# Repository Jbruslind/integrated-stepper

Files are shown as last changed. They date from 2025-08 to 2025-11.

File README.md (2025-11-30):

# Integrated Stepper

Full stepper motor control w/ local feedback and power conversion in a small package. The main idea was to have an all-in-one solution PCB which would run some open source FOC firmware (Simple-FOC for now) and have some higher level control through ethernet, CAN, or UART (CAN for now). 

Power and comms should be provided on the same wire harness either using RJ45 (original idea) or the XT30 + 2wire connector (current design) which allows for high voltage + current and 2wire comms. These can then be daisy chained to as many nodes as possible (limited by wire lengths for the most part)

## Key Features

- **High Precision:** Sub-degree positioning accuracy
- **Smooth Motion:** Advanced motion planning and acceleration control
- **Multiple Modes:** Position, velocity, and torque control modes
- **Microstepping:** Configurable microstepping for smooth operation
- **Communication:** UART, SPI, I2C, and CAN bus support

## Hardware Specifications

- **Current Rating:** Configurable current output up to 2A per phase continous
- **Voltage Range:** 8V to 35V operation
- **Microstepping:** Up to 256 microsteps per full step
- **Protection:** Overcurrent, overvoltage, and thermal protection

## Applications

- Industrial automation and conveyor systems
- Robotics and robot arms
- CNC machines and 3D printers
- Laser positioning systems
- Research and prototyping

## License

This project is open source and available under the MIT License.

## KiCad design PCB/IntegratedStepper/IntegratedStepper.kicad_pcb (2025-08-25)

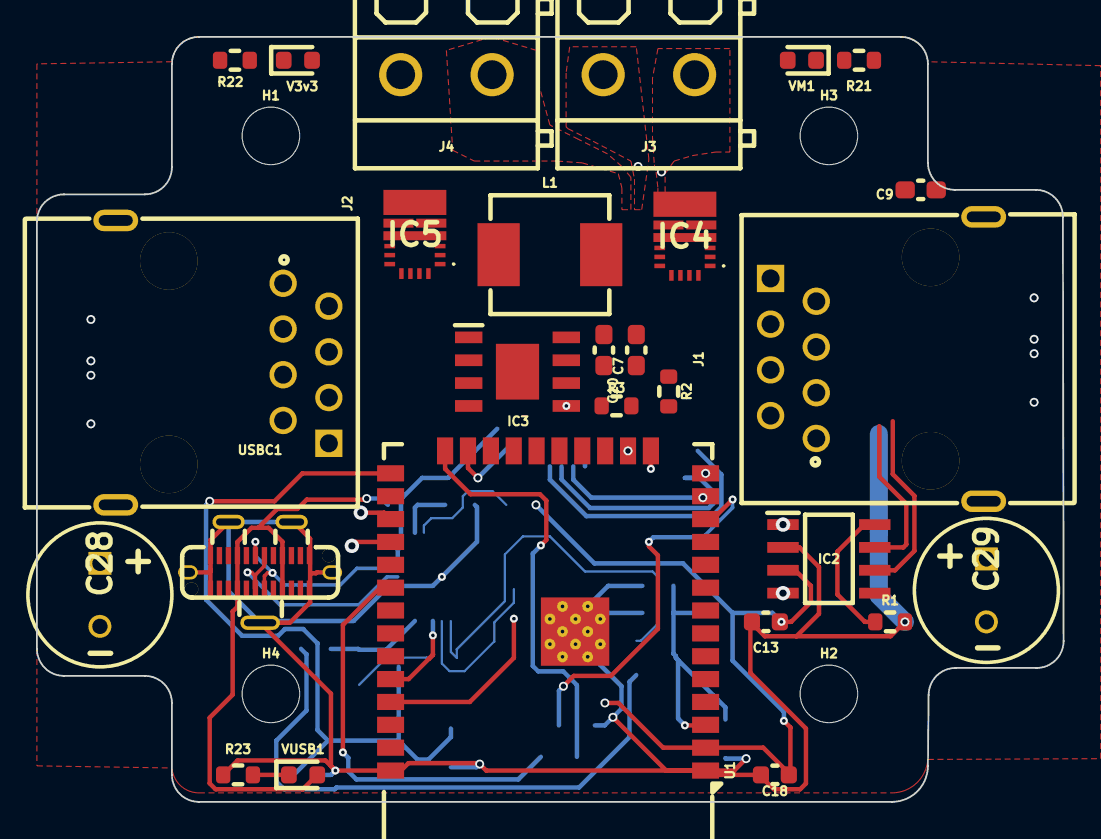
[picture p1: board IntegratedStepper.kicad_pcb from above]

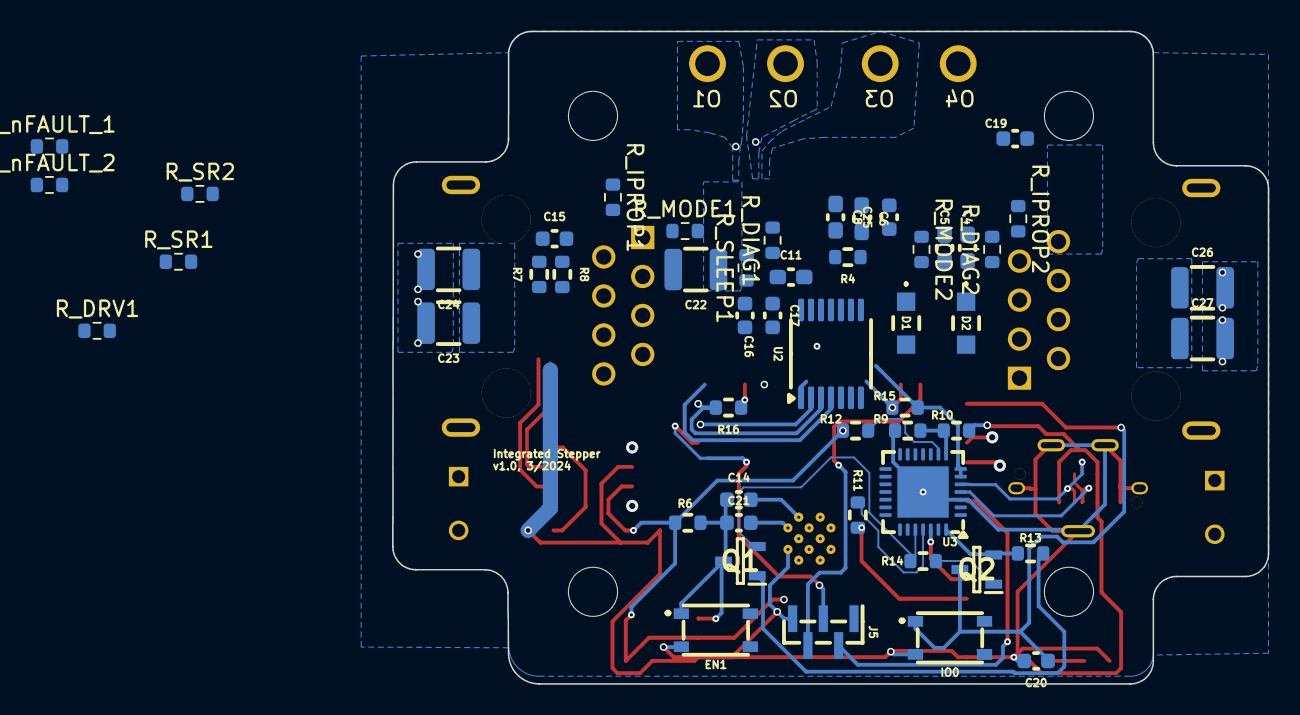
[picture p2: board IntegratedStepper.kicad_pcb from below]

Board: 4 copper layers, 57.0 x 42.5 mm, 82 parts (51 on the bottom side), 58 nets.

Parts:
C4, C7, C10: 10uf; C_0603_1608Metric_Pad1.08x0.95mm_HandSolder
C5, C9: 1uF; C_0603_1608Metric_Pad1.08x0.95mm_HandSolder
C6, C8: 100nf; C_0603_1608Metric_Pad1.08x0.95mm_HandSolder
C11: 0.1uF; C_0603_1608Metric_Pad1.08x0.95mm_HandSolder
C13, C14, C17, C18, C20, C21: 0.1uF; C_0603_1608Metric
C15: 4.7nF; C_0603_1608Metric
C16, C19, C25: 10uF; C_0603_1608Metric
C22, C23: 22uF; C_1210_3225Metric
C24, C26, C27: 10uF; C_1210_3225Metric
C28, C29: 100uF; CAPPRD350W65D800H1650
D1, D2: PMEG6020ER,115; PMEG6020ER115
EN1: PTS815_SJG_250_SMTR_LFS; PTS815SJM250SMTRLFS
H1, H2, H3, H4: MountingHole_Pad; MountingHole_3.2mm_M3
IC2: SN65HVD230DR; SOT127P600X175-8N
IC3: LMR38020FSQDDARQ1; SOIC127P600X170-9N
IC4, IC5: DRV8243HQRXYRQ1
IO0: PTS815_SJG_250_SMTR_LFS; PTS815SJM250SMTRLFS
J1, J2: 8P8C; RJ45-TH_KH-RJ45-58-8P8C
J3, J4: Screw_Terminal_01x02; CONN-TH_P5.08_KF128-5.08-2P
J5: Conn_01x05_Socket; PinHeader_1x05_P1.00mm_Vertical_SMD_Pin1Left
L1: 10uH; IND-SMD_L7.2-W6.6_GPSR07X0
Q1, Q2: SS8050-G; SOT95P240X115-3N
R1, R6, R13, R14: 10k; R_0603_1608Metric
R2: 154k; R_0603_1608Metric
R3, R4: 64.9k; R_0603_1608Metric
R7, R8: 60; R_0603_1608Metric
R9: 47.5k; R_0603_1608Metric
R10: 22.1k; R_0603_1608Metric
R11: 10; R_0603_1608Metric
R12, R15, R16: 2k; R_0603_1608Metric
R21: 10K; R_0603_1608Metric
R22, R23: 500; R_0603_1608Metric
R_DIAG1, R_DIAG2: 8.2k; R_0603_1608Metric
R_DRV1: 2k; R_0603_1608Metric
R_IPROP1, R_IPROP2: 820; R_0603_1608Metric
R_MODE1, R_MODE2: 8.2k; R_0603_1608Metric
R_SLEEP1: 2k; R_0603_1608Metric
R_SR1, R_SR2: 8.2k; R_0603_1608Metric
R_nFAULT_1, R_nFAULT_2: 2k; R_0603_1608Metric
U1: ESP32-WROOM-32E; ESP32-WROOM-32D
U2: AS5048A; TSSOP-14_4.4x5mm_P0.65mm
U3: CP2102N-Axx-xQFN28; QFN-28-1EP_5x5mm_P0.5mm_EP3.35x3.35mm
USBC1: TYPE-C 3.1_C168690; USB-C-SMD_TYPE-C-USB-3
V3v3: LED; LED_0603_1608Metric
VM1: LED; LED_0603_1608Metric
VUSB1: LED; LED_0603_1608Metric

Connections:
3V3_VCC: C7.1, C8.1, C9.1, C10.1, C13.1, C16.1, C17.1, C18.1, C19.1, IC2.3 (VCC), J5.1, L1.2, R2.1, R6.1, R12.2, R15.2, R_SLEEP1.1, R_nFAULT_1.2, R_nFAULT_2.2, U1.2 (VDD), U2.11 (VDD5V), U2.12 (VDD3V), U3.6 (VDD), U3.7 (VREGIN), V3v3.2 (A)
/3V3_VReg/VM: C22.1, C23.1, C24.1, C25.1, C26.1, C27.1, C28.1 (+), C29.1 (+), D1.2 (A), IC4.4 (VM), IC5.4 (VM), J1.1, J1.2, J2.1, J2.2, VM1.2 (A)
/CAN_Transciever/CAN_RX: IC2.4 (R), U1.28 (IO17)
/CAN_Transciever/CAN_TX: IC2.1 (D), U1.27 (IO16)
/DRV8844/DRVOFF: IC4.8 (DRVOFF), IC5.8 (DRVOFF), R_DRV1.2, U1.26 (IO4)
/DRV8844/IN1: IC4.9 (EN/IN1), U1.10 (IO25)
/DRV8844/IN2: IC4.10 (PH/IN2), U1.11 (IO26)
/DRV8844/IN3: IC5.9 (EN/IN1), U1.9 (IO33)
/DRV8844/IN4: IC5.10 (PH/IN2), U1.8 (IO32)
/DRV8844/NFAULT_1: IC4.1 (NFAULT), R_nFAULT_1.1, U1.31 (IO19)
/DRV8844/NFAULT_2: IC5.1 (NFAULT), R_nFAULT_2.1, U1.37 (IO23)
/DRV8844/NSLEEP: IC4.3 (NSLEEP), IC5.3 (NSLEEP), R_SLEEP1.2, U1.29 (IO5)
/DRV8844/OUT1: IC4.7 (OUT1), J3.1
/DRV8844/OUT2: IC4.5 (OUT2), J3.2
/DRV8844/OUT3: IC5.7 (OUT1), J4.1
/DRV8844/OUT4: IC5.5 (OUT2), J4.2
/ESP32_MCU/ENC+: J5.3, U1.12 (IO27)
/ESP32_MCU/ENC-: J5.2, U1.30 (IO18)
/ESP32_MCU/ENC_IND: J5.4, U1.24 (IO2)
/ESP32_MCU/M_CS0: R15.1, U1.23 (IO15), U2.1 (~CSn)
/ESP32_MCU/M_MISO: R16.2, U1.14 (IO12), U2.3 (MISO)
/ESP32_MCU/M_MOSI: U1.16 (IO13), U2.4 (MOSI)
/ESP32_MCU/M_SCLK: U1.13 (IO14), U2.2 (CLK)
CANH: IC2.6 (CANL), J1.5, J2.5, R7.1
CANL: IC2.7 (CANH), J1.4, J2.4, R8.2
DTR: Q2.2 (E), R13.1, U3.28 (~DTR)
EN: C14.1, C21.1, EN1.1 (COM_1), Q1.3 (C), R6.2, U1.3 (EN)
GND: C4.1, C5.1, C6.1, C7.2, C8.2, C9.2, C10.2, C13.2, C14.2, C15.2, C16.2, C17.2, C18.2, C19.2, C20.2, C21.2, C22.2, C23.2, C24.2, C25.2, C26.2, C27.2, C28.2 (-), C29.2 (-), EN1.3 (NO_1), IC2.2 (GND), IC3.1 (GND), IC3.9 (EP), IC4.6 (GND), IC5.6 (GND), IO0.3 (NO_1), J1.3, J1.6, J2.3, J2.6, J5.5, R1.2, R3.2, R4.2, R9.2, R16.1, R21.1, R22.1, R23.1, R_DIAG1.1, R_DIAG2.1, R_DRV1.1, R_IPROP1.2, R_IPROP2.2, R_MODE1.1, R_MODE2.1, R_SR1.1, R_SR2.1, U1.1 (GND), U1.15 (GND), U1.38 (GND), U1.39 (GND), U2.13 (GND), U3.3 (GND), U3.29 (GND), USBC1.0, USBC1.A1, USBC1.A12, USBC1.B1, USBC1.B12
IO0: C20.1, IO0.1 (COM_1), Q2.3 (C), U1.25 (IO0)
IPROPI_1: IC4.2 (IPROPI), R_IPROP1.1, U1.6 (IO34)
IPROPI_2: IC5.2 (IPROPI), R_IPROP2.1, U1.7 (IO35)
unnamed: C15.1, R7.2, R8.1
unnamed: IC2.8 (RS), R1.1
unnamed: C11.1, IC3.7 (BOOT)
unnamed: IC3.5 (FB), R2.2, R3.1
unnamed: IC3.4 (RT/SYNC), R4.1
unnamed: C11.2, IC3.8 (SW), L1.1
unnamed: IC4.11 (DIAG), R_DIAG1.2
unnamed: IC4.14 (MODE), R_MODE1.2
unnamed: IC4.12 (SR), R_SR1.2
unnamed: IC5.11 (DIAG), R_DIAG2.2
unnamed: IC5.14 (MODE), R_MODE2.2
unnamed: IC5.12 (SR), R_SR2.2
unnamed: Q1.1 (B), R13.2
unnamed: Q2.1 (B), R14.2
unnamed: R11.2, U1.35 (TXD0/IO1)
unnamed: R9.1, R10.1, U3.8 (VBUS)
unnamed: R12.1, U3.9 (~RST)
unnamed: R22.2, V3v3.1 (K)
unnamed: R21.2, VM1.1 (K)
unnamed: R23.2, VUSB1.1 (K)
RTS: Q1.2 (E), R14.1, U3.24 (~RTS)
RX: U1.34 (RXD0/IO3), U3.26 (TXD)
TX: R11.1, U3.25 (RXD)
USB_D+: U3.4 (D+), USBC1.A6, USBC1.B6
USB_D-: U3.5 (D-), USBC1.A7, USBC1.B7
VIN: C4.2, C5.2, C6.2, D1.1 (K), D2.1 (K), IC3.2 (EN), IC3.3 (VIN)
V_USB: D2.2 (A), R10.2, USBC1.A4, USBC1.A9, USBC1.B4, USBC1.B9, VUSB1.2 (A)
